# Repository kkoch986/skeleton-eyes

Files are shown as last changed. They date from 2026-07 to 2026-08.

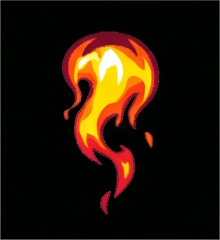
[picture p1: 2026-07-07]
firmware/sprites/frame_11.png

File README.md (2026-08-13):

# Skeleton Eye



Dual 1.28" TFT animatronic eyes with an I2C-controlled management board.

## Repository Layout

```
skeleton-eye2/
├── firmware/               # ESP32-S3 eye display controller
│   └── src/                # Procedural + sprite rendering, I2C slave, WiFi/OTA
├── lib/eye_control/        # C client library for controlling the eyes over I2C
├── management-board/       # ESP32-C3 I2C master controller
│   ├── src/eye_controller.ino  # Serial → I2C bridge
│   └── eye.sh                  # Send commands via USB serial
├── pcb/                    # Gerber files + drill files for the custom PCB
├── cad/                    # Frame/cover CAD files (DXF + STEP)
└── wiring.svg              # Wiring diagram
```

## Hardware

| Component | Board | Role |
|---|---|---|
| Eye display controller | ESP32-S3 (LOLIN S3 Mini) | Drives 2× GC9A01 displays, I2C slave at `0x42` |
| Management board *(optional)* | ESP32-C3 (LOLIN C3 Mini) | I2C master, serial command interface — mainly for testing |

**Note:** The left eye display is physically mounted upside down. The firmware handles the 180-degree rotation automatically.

### Wiring

Wiring diagram

See [`firmware/README.md`](firmware/README.md) for display pin connections and [`management-board/README.md`](management-board/README.md) for I2C wiring details.

## Bill of Materials

| Part | Qty | Link |
|---|:---:|---|
| ESP32 S3 Supermini | 1 | [AliExpress](https://www.aliexpress.us/item/3256807337873344.html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) |
| 24.8mm Round Lens | 2 | [AliExpress](https://www.aliexpress.us/item/3256803507484638.html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) |
| 1.28" Round TFT display module | 2 | [AliExpress](https://a.aliexpress.com/_m0m5OIX) |
| 4-pin JST Cable (10cm) | 1 | [AliExpress](https://www.aliexpress.us/item/3256812395686145.html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) |
| Custom PCB | 1 | [Gerbers](pcb/) |
| 7-pin Male header | 1 | [AliExpress](https://www.aliexpress.us/item/2255800801798474.html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) |
| 4-pin Female JST 2.54mm connector | 1 | [AliExpress](https://www.aliexpress.us/item/3256806894018733.html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) |
| 3D printed cover | 1 | [CAD](cad/) |
| M3 x 16mm cap head machine screw | 1 | — |
| M3 Nut | 1 | — |

## Quick Start

### Prerequisites

- PlatformIO CLI (`pip install platformio`)
- Python 3 with Pillow (`pip install Pillow`) for custom sprite conversion

### Build and Upload

```bash
# Build and upload firmware
cd firmware && make upload

# Optional: build and upload management board (for testing)
cd management-board && make upload
```

## Features

- **Dual rendering modes**: Procedural 3D eye rendering with lighting, eyelids, and reflections, or pre-rendered sprite animations
- **I2C external control**: Full remote control over I2C bus with smooth gaze, blink, squint, and color commands
- **WiFi OTA updates**: Over-the-air firmware updates with progress display on the eyes
- **C client library**: Drop-in C library for integrating eye control into your own firmware projects
- **Serial interface**: Interactive command shell via USB serial or the included `eye.sh` script

See the subdirectory READMEs for serial commands, I2C protocol details, and sprite development.

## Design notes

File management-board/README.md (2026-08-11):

# I2C Controller for Skeleton Eye

*Optional* — this board is mainly for testing and manual control. The eyes run standalone; the management board is only needed when you want to drive them interactively.

Controls the skeleton-eye animatronic eye displays via I2C from an ESP32-C3 (or any Arduino-compatible I2C master).

## I2C Protocol

The eye board acts as an I2C slave at address **`0x42`** (100kHz). All multi-byte values are little-endian.

See the [firmware README](../firmware/README.md#i2c-slave-address-0x42) for the full I2C command table.

## Build & Upload

```bash
make build      # compile
make upload     # flash to ESP32-C3
make monitor    # serial console
make run        # build + upload + monitor
```

## Wiring

- Controller SDA (GPIO8) → Eye board SDA (GPIO4)
- Controller SCL (GPIO9) → Eye board SCL (GPIO7)
- Common GND

## Serial Commands

| Command | Description |
|---|---|
| `look <x> <y> [s]` / `look center\|left\|right\|up\|down` | Smooth gaze |
| `jump <x> <y>` / `jump center\|left\|right\|up\|down` | Instant position |
| `blink [ms]` | Trigger blink |
| `squint <0-255>` | Set squint level |
| `unsquint` | Reset squint to 0 |
| `sclera <r g b\|hex>` | Sclera color (3×0-255 or 4-digit hex) |
| `iris <r g b\|hex>` | Iris color |
| `curve <f> <m> <s>` | Eyelid curve params (0-255) |
| `autoblink on\|off` | Enable/disable auto blink |
| `autoblinkspeed <ms>` | Set auto-blink interval |
| `smoothing fast\|medium\|slow\|<0-255>` | Gaze smoothing speed |
| `wifi ssid\|pass\|connect\|status\|forget` | WiFi/OTA control |
| `idle` | Release I2C control |
| `emotion <name>` | angry, sleepy, surprised, neutral |
| `sprite on\|off` | Toggle render mode |
| `sprite <n>` | Display sprite by index (0-8, 255=blank) |
| `spritestatus` | Query current render mode |
| `animate <ms> <i>...` / `stop` | Loop sprite frames / stop animation |
| `text <string>` / `text off` | Display / clear text on the eye screen |
| `textcolor <r g b\|hex>` | Text color (3×0-255 or 4-digit hex) |
| `textbg <r g b\|hex>` | Text background color |
| `status` | Read full eye status (31-byte status block) |
| `probe` | Check I2C connection |
| `i2cscan` | Scan I2C bus |
| `demo` | Run demo sequence |
| `reset` | Reset to autonomous mode |
| `resetdevice` | Reboot ESP32 eye board |
| `help` / `?` | Show help |

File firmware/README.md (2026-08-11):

# Skeleton Eyes - ESP32-S3 Animatronic Display

ESP32-S3 project for dual 1.28" TFT displays creating realistic animated eyes with I2C external control support.

## Hardware

| Component | Connection |
|---|---|
| Left Eye CS  | IO13 |
| Right Eye CS | IO9 |
| Shared RST | IO12 |
| Shared DC | IO8 |
| Shared SDA | IO11 (MOSI) |
| Shared SCL | IO10 (SCLK) |
| I2C SDA | IO4 |
| I2C SCL | IO7 |

## Quick Start

```bash
make              # Build
make upload       # Upload to device
make monitor      # View serial output
```

### Serial Commands (USB)

| Key | Action |
|-----|---|
| `s` | Toggle sprite mode |
| `b` | Trigger blink |
| `l`/`r`/`u`/`d` | Look left/right/up/down |
| `[`/`]` | Squint open/close |
| `h` | Print help |
| `w`/`B`/`L`/`G`/`H`/`R` | Sclera white/blue/light/green/red/iris red |

## Features

### Dual Rendering Modes

- **Procedural**: Real-time mathematical eye rendering with 3D lighting, eyelids, and reflections
- **Sprite**: Pre-rendered compressed sprite animations with procedural blink overlay

### I2C Slave (Address 0x42)

The eye board acts as an I2C slave. Commands override autonomous mode until a reset command.

| Cmd | Name | Params | Description |
|-----|---|---|---|
| 0x01 | `LOOK` | x (i16), y (i16) | Set gaze direction |
| 0x02 | `BLINK` | duration (u16) | Trigger blink (ms) |
| 0x03 | `SQUINT` | level (u8) | 0 (open) — 255 (closed) |
| 0x06 | `CURVE_PARAMS` | falloff (u8), min (u8), strength (u8) | Eyelid curve (0-255 each → 0.0-1.0) |
| 0x07 | `STATUS` | (read 31 bytes) | Full status block — gaze, squint, mode, colors, curve, blink, current position |
| 0x08 | `RESET` | — | Return to autonomous mode |
| 0x09 | `SCLERA_RGB` | color (u16 le) | Sclera color as RGB565 |
| 0x0A | `IRIS_RGB` | color (u16 le) | Iris color as RGB565 (dark variant derived) |
| 0x0B | `AUTO_BLINK` | enable (u8) | 1=on, 0=off |
| 0x0C | `IDLE` | — | Release I2C control, resume autonomous movement |
| 0x0D | `JUMP` | x (i16), y (i16) | Instant position (no smoothing) |
| 0x0E | `SMOOTHING` | factor (u8) | 0-255, default ~25 |
| 0x0F | `WIFI_SSID` | null-terminated string | Set WiFi SSID |
| 0x10 | `WIFI_PASS` | null-terminated string | Set WiFi password |
| 0x11 | `WIFI_CONNECT` | — | Connect to WiFi (enables OTA) |
| 0x12 | `WIFI_FORGET` | — | Clear stored WiFi credentials |
| 0x13 | `WIFI_STATUS` | (read) | Returns 1 byte: 0=disconnected, 1=connecting, 2=connected |
| 0x14 | `RESET_DEVICE` | — | Reboot ESP32 |
| 0x15 | `AUTO_BLINK_SPEED` | interval (u16 le) | ms between auto-blinks |
| 0x16 | `SPRITE_MODE` | enable (u8) | 1=sprite, 0=procedural |
| 0x17 | `GET_MODE` | (read) | Returns 1 byte: current render mode |
| 0x18 | `SET_SPRITE` | index (u8) | 0-63, 255 = none |
| 0x19 | `DISPLAY_TEXT` | string (max 62) | Display text wrapped on the eye screen |
| 0x1A | `CLEAR_TEXT` | — | Hide text overlay |
| 0x1B | `TEXT_COLOR` | color (u16 le) | Text color as RGB565 |
| 0x1C | `TEXT_BG` | color (u16 le) | Text background color as RGB565 |

## Sprite Development

1. Place 240×240 PNGs in `sprites/` — sorted alphabetically, indexed 0, 1, 2, ...
2. `make sprites` — convert to RLE-compressed sprite data at full resolution
3. `make sprites-half` — convert at 120×120, upscaled 2× at runtime (~4× less flash)
4. Select by index via I2C command `0x18` or the management board's `sprite on` command

## Performance

- **Frame rate**: 30 FPS
- **SPI speed**: 80MHz
- **RAM**: ~86%, **Flash**: ~64%

## Project Structure

```
firmware/
├── src/main.cpp              # Main application + I2C slave
├── src/generated_sprites.h   # Sprite data (generated)
├── sprites/                  # Source images (240×240 PNG)
├── convert_sprites.py        # Image → sprite data converter
├── platformio.ini            # Build configuration
└── Makefile                  # Build automation
```

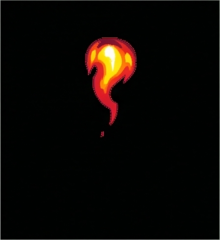
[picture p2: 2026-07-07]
firmware/sprites/frame_00.png

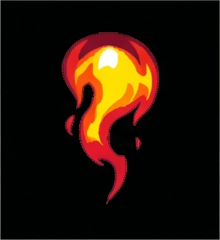
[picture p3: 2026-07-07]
firmware/sprites/frame_07.png

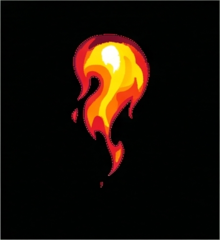
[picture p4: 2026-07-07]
firmware/sprites/frame_03.png

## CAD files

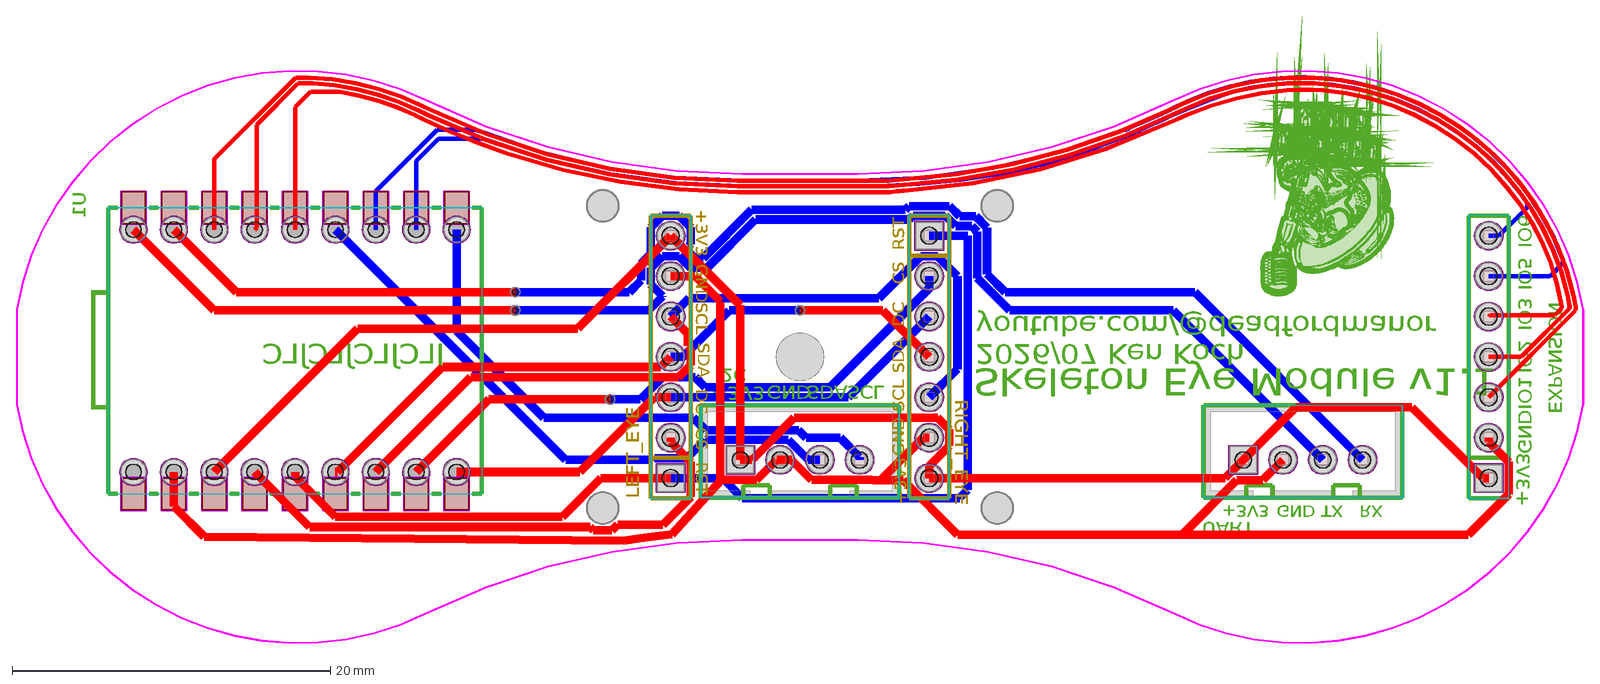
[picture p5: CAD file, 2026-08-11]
cad/board.dxf
Skeleton Eye Module v1.1
2026/07 Ken Koch
JLCJLCJLCJLC
youtube.com/@deadfordmanor
+3V3
GND
TX
RX
IO1
IO2
IO3
IO5
IO6
SDA
SCL
I2C
UART
EXPANSION
U1
RST
CS
DC
RIGHT_EYE
LEFT_EYE

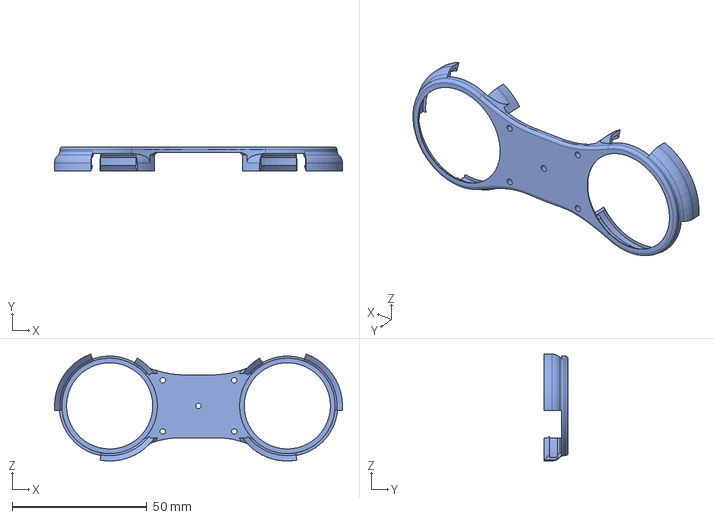
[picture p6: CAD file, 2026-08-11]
cad/skeleton-eyes-fram.step
107.0 x 9.00 x 39.7 mm

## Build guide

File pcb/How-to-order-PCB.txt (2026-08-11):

How to Order PCB

Please refer to:
https://prodocs.easyeda.com/en/pcb/order-order-pcb/index.html

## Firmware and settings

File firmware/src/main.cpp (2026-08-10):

/*
 * Skeleton Eye Display Controller
 */

#include <Arduino.h>
#include <SPI.h>
#include <Wire.h>

#include "globals.h"
#include "display.h"
#include "eye_renderer.h"
#include "sprites.h"
#include "i2c_commands.h"
#include "ota_display.h"
#include "wifi_manager.h"

SPIClass *hspi = &SPI;
SPISettings spi_settings(80000000, MSBFIRST, SPI_MODE0);

uint16_t left_eye_buffer[DISPLAY_WIDTH * DISPLAY_HEIGHT];
uint16_t right_eye_buffer[DISPLAY_WIDTH * DISPLAY_HEIGHT];

SpriteFrame sprite_frames[MAX_SPRITE_FRAMES];
uint8_t sprite_count = 0;
int8_t current_sprite = -1;
bool sprite_mode = false;

lighting_t eye_lighting;
float global_squint = 0.0f;
float left_squint = 0.0f;
float right_squint = 0.0f;
float curve_falloff = 0.05f;
float curve_minimum = 0.6f;
float closure_strength = 1.00f;

uint16_t current_sclera_color = COLOR_SCLERA;
uint16_t current_iris_dark_color = COLOR_IRIS_DARK;
uint16_t current_iris_med_color = COLOR_IRIS_MED;

volatile bool i2c_command_received = false;
volatile uint8_t i2c_buffer[64];
volatile uint8_t i2c_buffer_index = 0;
volatile bool i2c_external_control = false;
int16_t i2c_look_x = 0;
int16_t i2c_look_y = 0;
float i2c_squint_level = 0.0f;
bool i2c_blink_trigger = false;
bool auto_blink_enabled = false;
uint16_t auto_blink_interval = 3500;
int16_t current_look_x = 0;
int16_t current_look_y = 0;
int16_t target_look_x = 0;
int16_t target_look_y = 0;
float i2c_smoothing = 0.1f;
uint32_t i2c_blink_duration = 150;
bool i2c_initialized = false;
bool i2c_master_detected = false;

String wifi_ssid = "";
String wifi_pass = "";
bool wifi_should_connect = false;
bool wifi_connecting = false;
bool wifi_connected = false;
unsigned long wifi_connect_start = 0;

bool ota_display_active = false;
int ota_fill_rows = 0;
bool waiting_display_shown = false;

bool display_text_active = false;
uint16_t display_text_color = OTA_COLOR_TEXT;
uint16_t display_text_bg = OTA_COLOR_BLACK;

bool force_eye_repaint = false;

void setup() {
  Serial.begin(115200);
  delay(5000);

  pinMode(LEFT_EYE_CS, OUTPUT);
  pinMode(RIGHT_EYE_CS, OUTPUT);
  pinMode(SHARED_RST, OUTPUT);
  pinMode(SHARED_DC, OUTPUT);
  pinMode(BOOT_BUTTON, INPUT_PULLUP);
  pinMode(LED_PIN, OUTPUT);
  digitalWrite(LED_PIN, LOW);

  display_bus_init();

  hspi->begin(SHARED_SCL, 1, SHARED_SDA, -1);

  digitalWrite(SHARED_DC, LOW);
  digitalWrite(LEFT_EYE_CS, HIGH);
  digitalWrite(RIGHT_EYE_CS, HIGH);

  digitalWrite(SHARED_RST, HIGH);
  delay(10);
  digitalWrite(SHARED_RST, LOW);
  delay(50);
  digitalWrite(SHARED_RST, HIGH);
  delay(150);

  select_display(LEFT_EYE_CS);
  init_gc9a01();
  deselect_all();

  select_display(RIGHT_EYE_CS);
  init_gc9a01();
  deselect_all();

  load_sprite_data();
  randomSeed(analogRead(0));
  Serial.println("Eye display system ready!");

  renderer_init();
  init_i2c_system();
  wifi_init();
}

void loop() {
  uint32_t now = millis();

  static uint32_t last_heartbeat = 0;
  if (now - last_heartbeat > 5000) {
    last_heartbeat = now;
    Serial.printf("heartbeat i2c_init=%d master_seen=%d cmd_pending=%d\n",
                  i2c_initialized, i2c_master_detected, i2c_command_received);
  }

  wifi_update();
  process_i2c_command();
  boot_button_update();

  if (i2c_just_ready && now - i2c_ready_display_start > I2C_READY_DISPLAY_MS) {
    i2c_just_ready = false;
  }

  update_eyes();

  delay(1);
}

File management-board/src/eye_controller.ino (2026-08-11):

#include <Wire.h>

#define EYE_I2C_ADDR 0x42

#define I2C_SDA 8
#define I2C_SCL 9

#define CMD_LOOK          0x01
#define CMD_BLINK         0x02
#define CMD_SQUINT        0x03
#define CMD_CURVE_PARAMS  0x06
#define CMD_STATUS        0x07
#define CMD_RESET         0x08
#define CMD_SCLERA_RGB    0x09
#define CMD_IRIS_RGB      0x0A
#define CMD_AUTO_BLINK    0x0B
#define CMD_IDLE          0x0C
#define CMD_JUMP          0x0D
#define CMD_SMOOTHING     0x0E
#define CMD_WIFI_SSID     0x0F
#define CMD_WIFI_PASS     0x10
#define CMD_WIFI_CONNECT  0x11
#define CMD_WIFI_FORGET   0x12
#define CMD_WIFI_STATUS   0x13
#define CMD_RESET_DEVICE  0x14
#define CMD_AUTO_BLINK_SPEED 0x15
#define CMD_SPRITE_MODE  0x16
#define CMD_GET_MODE     0x17
#define CMD_SET_SPRITE   0x18
#define CMD_DISPLAY_TEXT 0x19
#define CMD_CLEAR_TEXT   0x1A
#define CMD_TEXT_COLOR   0x1B
#define CMD_TEXT_BG      0x1C

#define RGB565(r, g, b) ((((r) >> 3) << 11) | (((g) >> 2) << 5) | ((b) >> 3))

#define SCLERA_DEFAULT 0xF7DE
#define IRIS_DEFAULT   0x4A49

uint16_t parseRGB(String s) {
  int first = s.indexOf(' ');
  if (first > 0) {
    int second = s.indexOf(' ', first + 1);
    if (second > 0) {
      return RGB565(
        (uint8_t)constrain(s.substring(0, first).toInt(), 0, 255),
        (uint8_t)constrain(s.substring(first + 1, second).toInt(), 0, 255),
        (uint8_t)constrain(s.substring(second + 1).toInt(), 0, 255)
      );
    }
  }
  return (uint16_t)strtol(s.c_str(), NULL, 16);
}

uint8_t parseSmoothing(String s) {
  s.toLowerCase();
  if (s == "fast")   return 127;
  if (s == "medium") return 25;
  if (s == "slow")   return 5;
  return (uint8_t)constrain(s.toInt(), 0, 255);
}

bool eye_connected = false;

#define MAX_ANIM_FRAMES 64
bool animating = false;
uint8_t anim_frames[MAX_ANIM_FRAMES];
uint8_t anim_frame_count = 0;
uint8_t anim_current_index = 0;
uint16_t anim_frame_delay = 0;
unsigned long anim_last_time = 0;

void stop_anim() {
  animating = false;
}

void setSpriteIndex(int idx, bool silent = false);

bool probe_eye() {
  Wire.beginTransmission(EYE_I2C_ADDR);
  byte err = Wire.endTransmission();
  eye_connected = (err == 0);
  return eye_connected;
}

void i2c_scan() {
  Serial.println("Scanning I2C bus...");
  int count = 0;
  for (uint8_t addr = 1; addr < 127; addr++) {
    Wire.beginTransmission(addr);
    byte err = Wire.endTransmission();
    if (err == 0) {
      Serial.printf("  Found device at 0x%02X", addr);
      if (addr == EYE_I2C_ADDR) Serial.print(" <-- eye board");
      Serial.println();
      count++;
    }
  }
  Serial.printf("Scan complete. %d device(s) found.\n", count);
}

void printHelp() {
  Serial.println();
  Serial.println("--- Eye Controller Commands ---");
  Serial.println("look <x> <y> [s]     Smooth gaze to position; optional smoothing");
  Serial.println("                       (fast/medium/slow or 0-255)");
  Serial.println("look center|left|right|up|down");
  Serial.println("jump <x> <y>         Instant gaze to position");
  Serial.println("jump center|left|right|up|down");
  Serial.println("blink [ms]           Trigger blink (default 200ms)");
  Serial.println("squint <0-255>       Squint level");
  Serial.println("unsquint             Squint = 0");
  Serial.println("sclera <r g b|hex>   Set sclera: 3 bytes (0-255) or 4-digit hex");
  Serial.println("iris <r g b|hex>     Set iris: 3 bytes (0-255) or 4-digit hex");
  Serial.println("curve <f> <m> <s>    Eyelid curve (falloff min strength 0-255)");
  Serial.println("autoblink on|off      Enable/disable autonomous blinking");
  Serial.println("autoblinkspeed <ms>    Set interval between auto-blinks (ms)");
  Serial.println("smoothing <val>      Smoothing speed: fast|medium|slow or 0-255");
  Serial.println("wifi ssid <name>     Set WiFi SSID");
  Serial.println("wifi pass <pass>     Set WiFi password");
  Serial.println("wifi connect         Connect to WiFi (enables OTA updates)");
  Serial.println("wifi status          Query WiFi connection status");
  Serial.println("wifi forget          Clear stored WiFi credentials");
  Serial.println("idle                  Return to autonomous eye movement");
  Serial.println("emotion name         angry, sleepy, surprised, neutral");
  Serial.println("status               Read eye status");
  Serial.println("probe                Check I2C connection");
  Serial.println("i2cscan              Scan I2C bus");
  Serial.println("demo                 Run demo sequence");
  Serial.println("reset                Return eyes to autonomous mode");
  Serial.println("resetdevice          Reboot the ESP32 eye board");
  Serial.println("sprite on|off        Enter/exit sprite render mode");
  Serial.println("sprite <n>           Display sprite by index (0-8, 255=blank)");
  Serial.println("spritestatus         Query current render mode");
  Serial.println("animate <ms> <i>...  Loop sprite indices at given speed");
  Serial.println("                     e.g. animate 100 0 1 2 3 4 5 6 7 8");
  Serial.println("stop                 Stop sprite animation");
  Serial.println("curve <f> <m> <s>    Eyelid curve (falloff min strength 0-255)");
  Serial.println("text <string>        Display text on eye screen (max 62 chars)");
  Serial.println("text off             Clear displayed text");
  Serial.println("textcolor <r g b|hex> Set text color (3 bytes or 4-digit hex)");
  Serial.println("textbg <r g b|hex>   Set text background color");
  Serial.println("help / ?             This help");
  Serial.println();
}

void setup() {
  Serial.begin(115200);
  delay(1000);
  Serial.println("Skeleton Eye I2C Controller");

  Wire.setPins(I2C_SDA, I2C_SCL);
  Wire.begin();
  Serial.printf("I2C pins: SDA=%d, SCL=%d\n", I2C_SDA, I2C_SCL);

  pinMode(LED_BUILTIN, OUTPUT);
  digitalWrite(LED_BUILTIN, LOW);

  for (int i = 0; i < 5; i++) {
    if (probe_eye()) break;
    delay(200);
  }

  if (eye_connected) {
    Serial.println("Eye board detected!");
    digitalWrite(LED_BUILTIN, HIGH);
  } else {
    Serial.println("WARNING: No eye board found on I2C bus! Type 'help' for commands.");
  }

  Serial.println("Commands: look, blink, squint, sclera, iris, emotion, reset, status, probe, i2cscan, help");
}

void loop() {
  if (Serial.available()) {
    String cmd = Serial.readStringUntil('\n');
    cmd.trim();
    stop_anim();
    processSerialCommand(cmd);
  }

  if (animating && millis() - anim_last_time >= anim_frame_delay) {
    anim_last_time = millis();
    setSpriteIndex(anim_frames[anim_current_index], true);
    anim_current_index++;
    if (anim_current_index >= anim_frame_count) {
      anim_current_index = 0;
    }
  }
}
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

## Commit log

2026-07-07 Firmware: dual-display animatronic eye controller for ESP32-S3
2026-07-07 I2C control: ESP32-C3 management board firmware and C client library
    The management board acts as a serial-to-I2C bridge running on an ESP32-C3,
    providing an interactive command interface for controlling the eye displays.
    Includes the portable eye_control C library for integrating I2C eye control
    into custom firmware projects, and the eye.sh serial CLI script.
2026-07-11 Project documentation and hardware overview
    Top-level README describing the dual-microcontroller architecture,
    hardware requirements, wiring references, and available subsystems.
2026-07-21 Add boot button WiFi toggle, I2C retry with visual feedback, LED status, and font fixes
    - Boot button (GPIO 0) toggles WiFi connect/disconnect with debounce
    - I2C init retries until bus clears (workaround for ESP32-S3 slave init contention)
    - Multi-strategy I2C init (direct, master-first, default pins)
    - Green flash on displays when I2C connects (3s, with new c/K font glyphs)
    - Status LED (GPIO 15) lights when I2C is ready
    - 5s heartbeat log for debug
    - Remove per-command I2C RX/TX logs to reduce hot-path overhead
    [main.cpp]
2026-07-21 Modularize firmware: extract main.cpp into focused modules
    Split the ~1870-line monolithic main.cpp into seven files:
    - globals.h — shared types, pin defines, extern declarations
    - display.{h,cpp} — GC9A01 SPI driver (send command/data, init, frame buffers)
    - eye_renderer.{h,cpp} — 3D procedural eye rendering + update_eyes() loop
    - sprites.{h,cpp} — sprite decompression, blink overlay, font/text rendering
    - i2c_commands.{h,cpp} — I2C slave init (with retry loop), command dispatch
    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
2026-08-10 Fix eye jitter under DMX load: async renderer, I2C command queue
    - Async renderer on core 0 with latest-wins frame gating (E2/E3):
    look >1px, blink >0.05, or color/squint/sprite change triggers a
    re-render; sprite re-rendered only on mode/frame/blink delta
    - I2C command ring buffer (16x68B) with atomic ISR enqueue and
    pop-one-per-loop processing; no more torn multi-byte payloads (E1)
    - Display bus mutex serializes SPI + shared eye buffers between the
    render task and loop-task draws (OTA/text); all send_frame_buffer
    call sites locked
    - Frame-rate-independent look smoothing on float accumulators so
    sub-pixel steps no longer truncate to zero; jump detection picks
    up hard-set look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
    [display.cpp, eye_renderer.cpp, globals.h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]
2026-08-11 Fix text wrapping on eye display: per-column rendering with circle-aware line breaks
    [ota_display.cpp]
2026-08-11 Add text display commands and full 31-byte status to C client and management board
2026-08-11 Add manufacturing files: PCB gerbers, CAD models, and schematic wiring diagram
    [Drill_NPTH_Through.DRL, Drill_PTH_Through.DRL, Drill_PTH_Through_Via.DRL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]
2026-08-11 Update docs: reduced BOM, repo layout with CAD/PCB, text I2C commands
2026-08-11 Move eye.sh into management-board
2026-08-11 Mark management board optional and testing-only
2026-09-16 Lock default build env to round GC9A01 build
    platformio.ini now sets [platformio] default_envs = esp32-s3-devkitc-1
    so a bare 'pio run'/'pio upload' targets the round 1.28" GC9A01 pair and
    cannot silently build or flash the ILI9341 retrofit envs. Those stay
    opt-in via explicit -e. Makefile default ENVIRONMENT unchanged (round) but
    now overridable with ENVIRONMENT=... for the retrofit boards.
2026-09-16 Implement ESP32 DevKit V1 + ILI9341 retrofit build
    Add a second build configuration driving two 2.4-inch ILI9341 panels
    (240x320) for the 12ft skeleton retrofit: board abstraction layer
    (board_config, boards/), panel driver abstraction (panels/, panel_config),
    and banded rendering so a 153KB 18-bit frame fits the classic ESP32's
    split heap. Round GC9A01 build stays the default and is behavior-identical.
    Includes two follow-up fixes: per-eye MADCTL rotation so the flipped panel
    presents upright, and restoring writePixels for the RGB565 frame push that
    the refactor's transferBytes had byte-swapped.
